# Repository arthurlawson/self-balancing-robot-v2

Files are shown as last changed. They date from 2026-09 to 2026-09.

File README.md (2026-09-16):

# 🤖 Self-Balancing Robot V2

### A Drivable Self-Balancing Robot That Screams When It Falls!

An advanced self-balancing robot utilizing the **ESP32-S3 (N16R8)** computing core, driven by a custom **Kalman Filter** and high-frequency **PID control loop** system.

This project features a fully **custom-designed main controller PCB, proudly sponsored and manufactured by JLCPCB**.

Built entirely within the PlatformIO ecosystem, this hardware platform integrates an MPU6050 IMU, DRV8833 motor driver, 2S LiPo battery safety logic, lighting, and onboard speaker playback systems.

---

## Core Features

*   **Advanced Estimation:** Custom Kalman Filter implementation paired with an MPU6050 IMU for precise roll angle determination.
*   **Wireless Remote Control:** Directional steering control handled over a dedicated **ESP-NOW** wireless connection.
*   **Motion:** Dual-motor balancing algorithms with custom gain scheduling to aid in active control.
*   **Hardware Protection:** Automated motor shutdown constraints to prevent destructive runaway crashes.
*   **Power Management:** Active voltage checks safeguarding the 2S LiPo system from dropping beneath unsafe cell margins.
*   **Audio & Visuals:** Integrated 2P edison filament LED's with status animations alongside audio playback to make the robot scream.

---

## Quick Navigation Hub

To get started with assembling or programming the robot, navigate to the specific setup guides below:

*   **[Firmware Setup & Deployment](./firmware/SETUP_GUIDE.md):** Complete code overview, configuration walkthrough for `config.h`, custom audio formatting parameters, and PlatformIO flashing instructions.
*   **[Hardware Production & Assembly](./hardware/SETUP_GUIDE.md):** Access to print-ready `.3mf` files, raw SolidWorks CAD models, custom KiCad schematics, and factory-ready Gerber packages.
*   **[Bill of Materials (BOM)](./hardware/BOM.md):** The complete physical and electrical component checklist required to buy, print, and manufacture the robot.

---

## Project License

This repository is distributed under a custom **Non-Commercial Open-Source License**. 

*   **Personal & Educational Use:** Freely allowed to modify, merge, and run the code/hardware assets.
*   **Commercial Use:** Strictly prohibited from being sold, leased, or utilized for paid product development without explicit written consent from the copyright holder.

*See the full terms inside the accompanying [LICENSE](./LICENSE) file.*

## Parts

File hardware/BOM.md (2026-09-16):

# Bill of Materials (BOM)

This document tracks all electronic, drivetrain, mechanical, and structural components required to fully manufacture and assemble the robot.

---

## 1. Core Electronics & Custom PCB Components

These components populate the custom controller PCB fabrications:
*   **Microcontroller:** ESP32-S3 (N16R8 Development Board variant)
*   **Inertial Measurement Unit (IMU):** MPU6050 Module (Breakout board style)
*   **Motor Driver Module:** DRV8833 Dual H-Bridge Motor Driver
*   **Power Regulation Module:** MPM3610 3.3V Buck Regulator (Highly efficient synchronous step-down)
*   **Peripherals:** Onboard 4-ohm Speaker, a 2P edison filament light setup connected to the top shelf
*   **Passives Checklist:** Assorted resistors (including voltage dividers for battery sensing tracking lines), capacitors, tactile buttons, and male/female header pins

---

## 2. Drivetrain & Power Systems

*   **Motors:** 2x TT Dual-Shaft DC Gearbox Motors (Yellow hobby style motors)
*   **Power Source:** 2S LiPo Battery (7.4V nominal, 8.4V max)
*   **Switching:** Main power toggle switch

---

## 3. Mechanical Fasteners

*   **Chassis Assembly:** M3 Hex Screws (Assorted lengths) and nuts, and M3 brass heat set inserts
*   **Motor Mount Fasteners:** M3 Screws and nuts compatible with standard TT motor chassis slots

---

## 4. Fabrication Components & Materials

*   **Custom PCB Manufacturing (`/electronics/fabrication`):** Main trace layout designed for manufacturing directly by **JLCPCB** using the provided `gerbers.zip` archive.
*   **Structural Rigid Printing Parts (`/cad/3d_prints`):** Printed entirely in **PLA+** for impact protection to withstand crashes when the robot falls over and screams.
    *   *Includes components:* BackPiece, FrontFacePiece, InnerChassis, LightDiffuser, MiddleHeadCover, TopShelf, and WheelRim.
*   **Traction Components (`/cad/3d_prints`):** `WheelTread.3MF` **must be manufactured in TPU** by **JLCPCB** to guarantee better balancing traction.

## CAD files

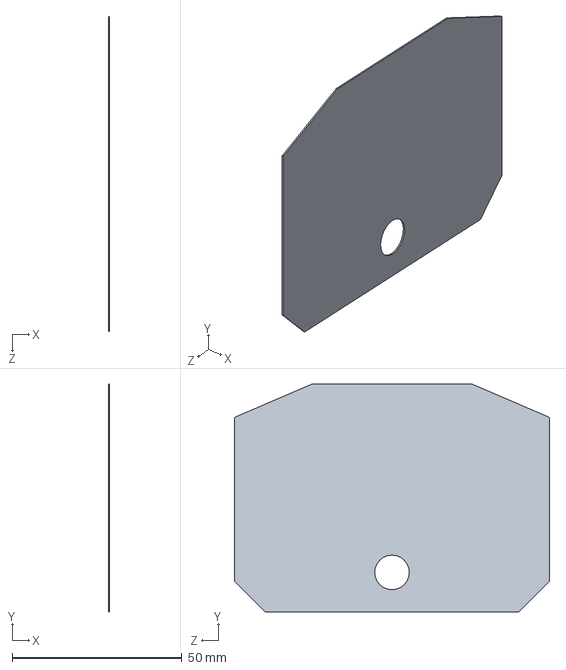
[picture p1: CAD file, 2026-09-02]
hardware/cad/source/solidwork_files/LightDiffuser.SLDPRT
0.4 x 67.2 x 92.9 mm

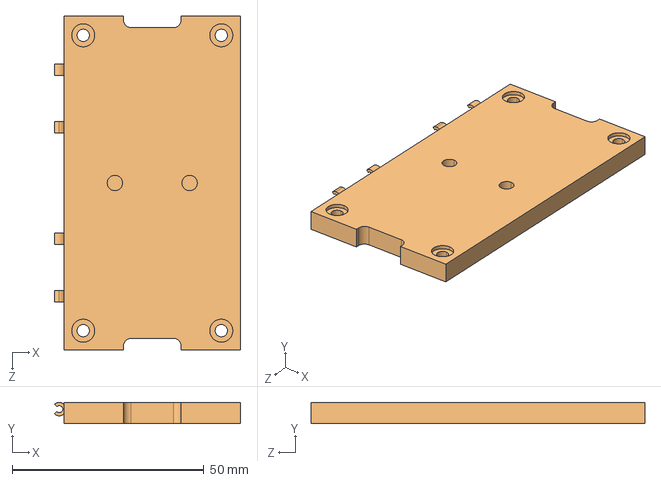
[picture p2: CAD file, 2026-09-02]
hardware/cad/source/step_files/TopShelf.STEP
48.5 x 5.58 x 87.0 mm

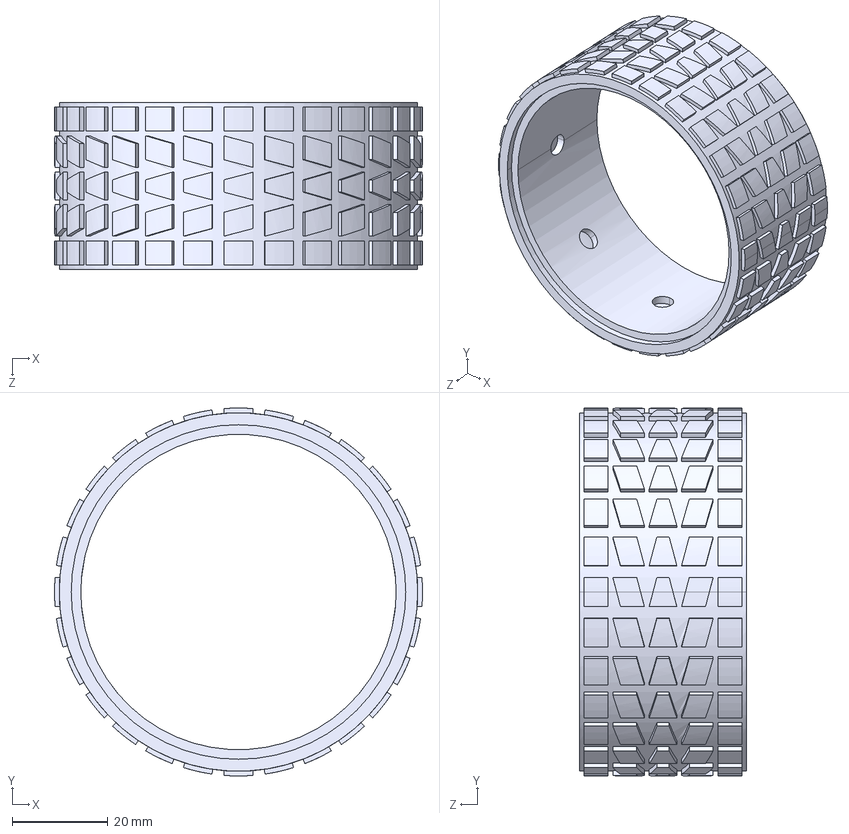
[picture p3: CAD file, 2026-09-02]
hardware/cad/source/step_files/WheelTread.STEP
77.0 x 77.0 x 35.0 mm

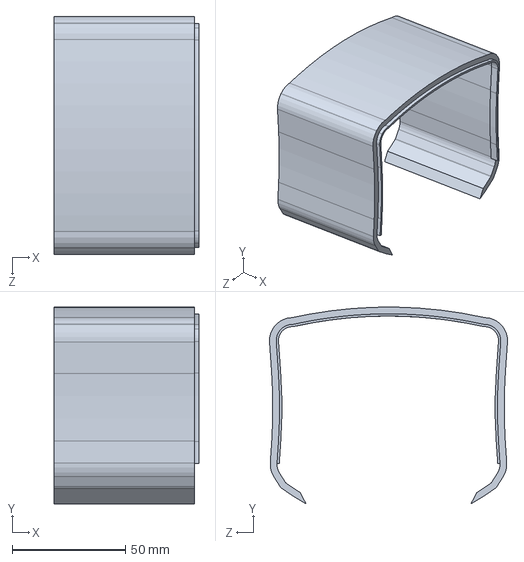
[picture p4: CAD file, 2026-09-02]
hardware/cad/source/solidwork_files/MiddleHeadCover.SLDPRT
64.0 x 86.9 x 105.1 mm

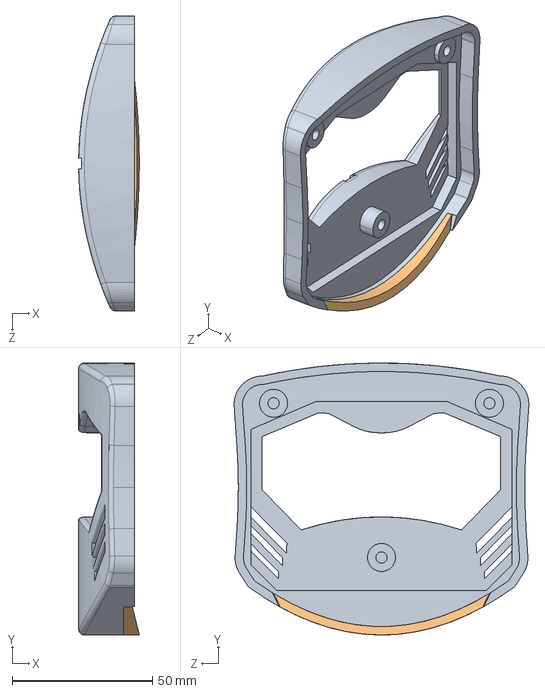
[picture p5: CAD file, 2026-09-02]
hardware/cad/source/step_files/FrontFacePiece.STEP
21.6 x 97.0 x 105.2 mm

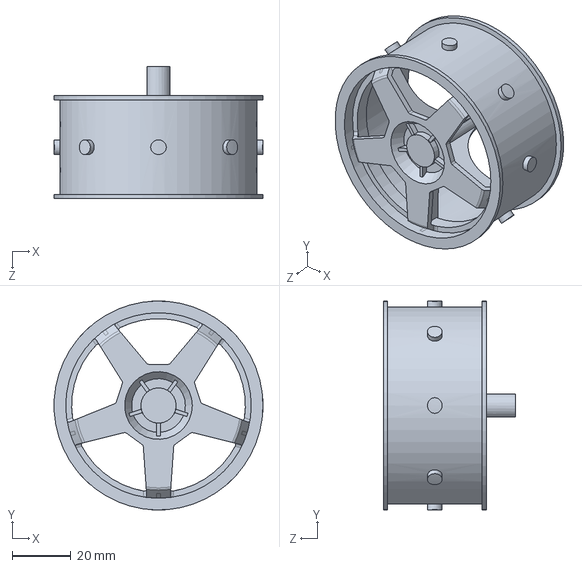
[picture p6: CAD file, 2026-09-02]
hardware/cad/source/solidwork_files/WheelRim.SLDPRT
71.0 x 71.0 x 45.0 mm

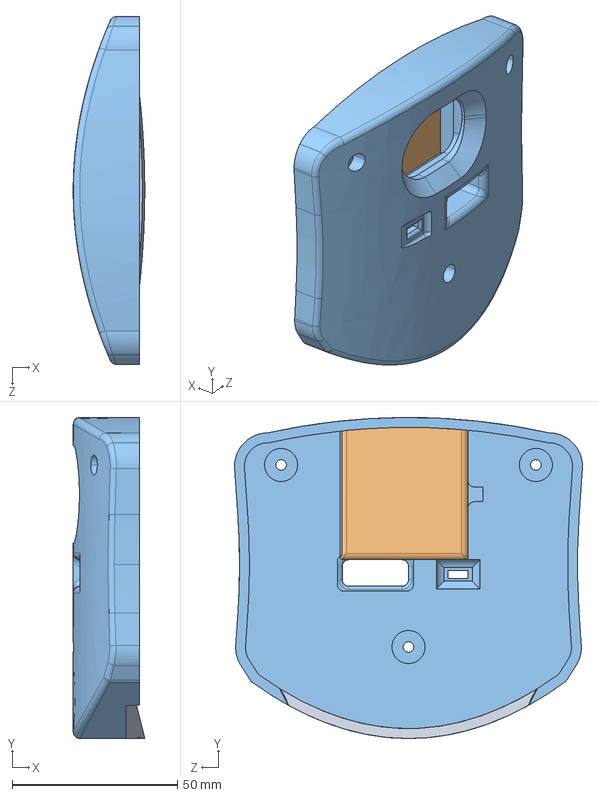
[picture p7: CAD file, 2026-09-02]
hardware/cad/source/step_files/BackPiece.STEP
21.7 x 97.0 x 105.2 mm

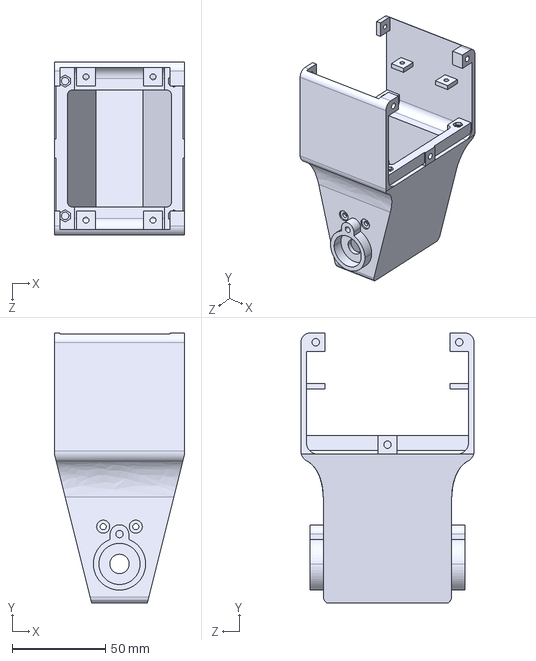
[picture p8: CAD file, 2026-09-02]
hardware/cad/source/step_files/InnerChassis.STEP
70.0 x 145.0 x 93.0 mm

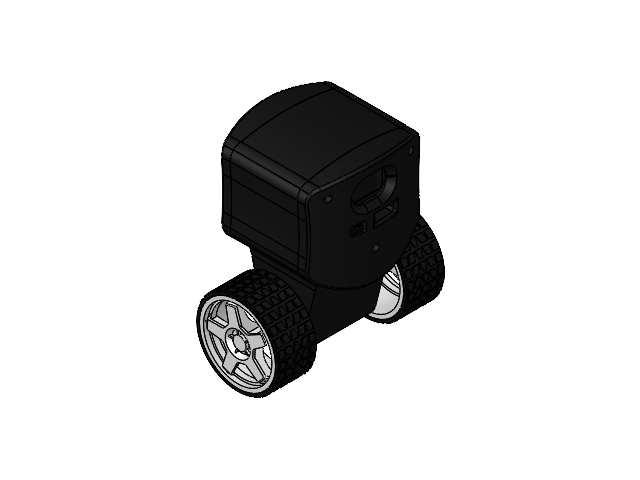
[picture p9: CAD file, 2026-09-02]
hardware/cad/source/solidwork_files/FullAssembly.SLDASM
InnerChassis
WheelRim x 2
WheelTread x 2
FrontFacePiece
CP_Radial_D63mm_P250mm.step
R_Axial_DIN0207_L63mm_D25mm_P762mm_Horizontal.step x 8
PinHeader_1x01_P254mm_Vertical.step x 8
PinHeader_1x02_P254mm_Vertical.step x 2
PinHeader_1x06_P254mm_Vertical.step x 2
C_Disc_D50mm_W25mm_P500mm.step x 3
PinHeader_1x08_P254mm_Vertical.step
TO-92_Inline_Narrow.step x 2
CP_Radial_D80mm_P380mm.step
PinHeader_1x04_P254mm_Vertical.step
esp32_self_balancing_robot_copper.step
esp32_self_balancing_robot_pad.step
esp32_self_balancing_robot_silkscreen.step
esp32_self_balancing_robot_silkscreen-0.step
esp32_self_balancing_robot_soldermask.step
esp32_self_balancing_robot_soldermask-1.step
esp32_self_balancing_robot_PCB.step
Gearbox.STEP x 2
output shaft.STEP x 2
motor.STEP x 2
LightDiffuser
BackPiece
HexNylonStandoff x 4
TopShelf
MiddleHeadCover

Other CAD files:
hardware/cad/source/solidwork_files/TopShelf.SLDPRT
hardware/cad/source/solidwork_files/WheelTread.SLDPRT
hardware/cad/source/step_files/LightDiffuser.STEP
hardware/cad/source/solidwork_files/BackPiece.SLDPRT
hardware/cad/source/solidwork_files/FrontFacePiece.SLDPRT
hardware/cad/source/step_files/MiddleHeadCover.STEP
hardware/cad/source/solidwork_files/InnerChassis.SLDPRT
hardware/cad/source/step_files/WheelRim.STEP
hardware/cad/3d_prints/BackPiece.3mf
hardware/cad/3d_prints/FrontFacePiece.3mf
hardware/cad/3d_prints/InnerChassis.3mf
hardware/cad/3d_prints/LightDiffuser.3mf
hardware/cad/3d_prints/MiddleHeadCover.3mf
hardware/cad/3d_prints/TopShelf.3mf
hardware/cad/3d_prints/WheelRim.3MF
hardware/cad/3d_prints/WheelTread.3MF

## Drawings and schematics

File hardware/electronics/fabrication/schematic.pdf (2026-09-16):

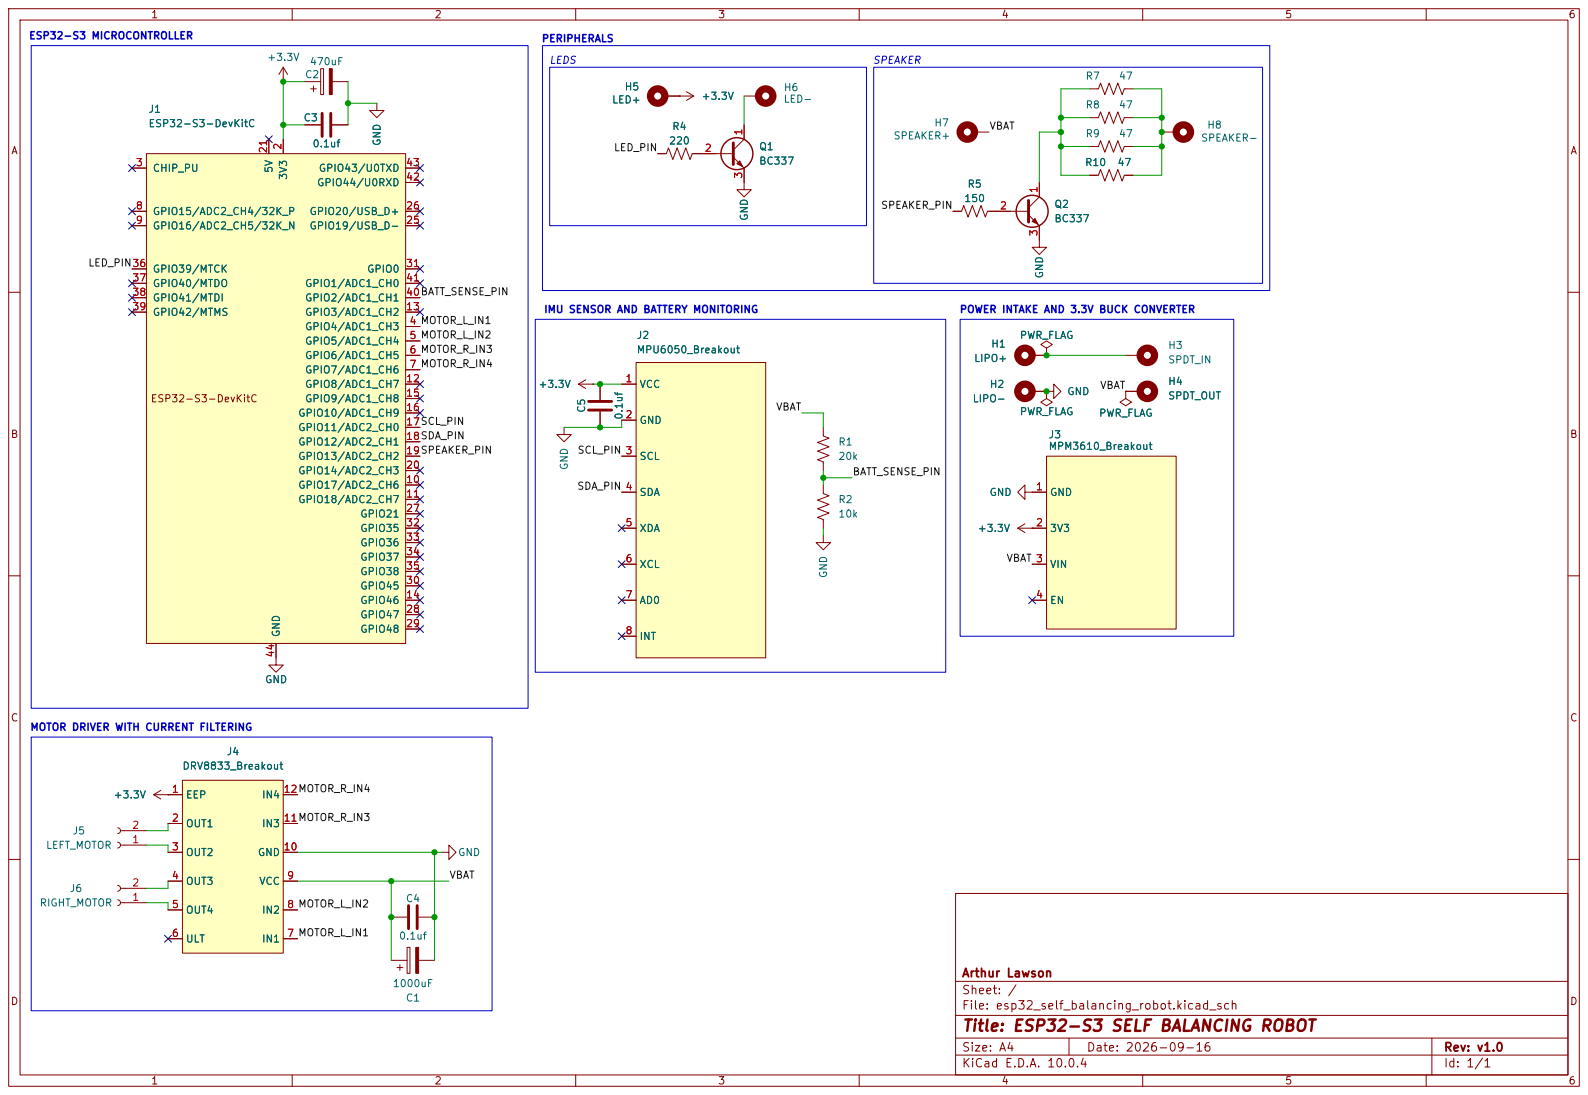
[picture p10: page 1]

PERIPHERALS MOTOR DRIVER WITH CURRENT FILTERING

Arthur Lawson
Sheet: /
File: esp32_self_balancing_robot.kicad_sch
Title: ESP32-S3 SELF BALANCING ROBOT

Size: A4 | Rev: v1.0
KiCad E.D.A. 10.0.4 | Id: 1/1

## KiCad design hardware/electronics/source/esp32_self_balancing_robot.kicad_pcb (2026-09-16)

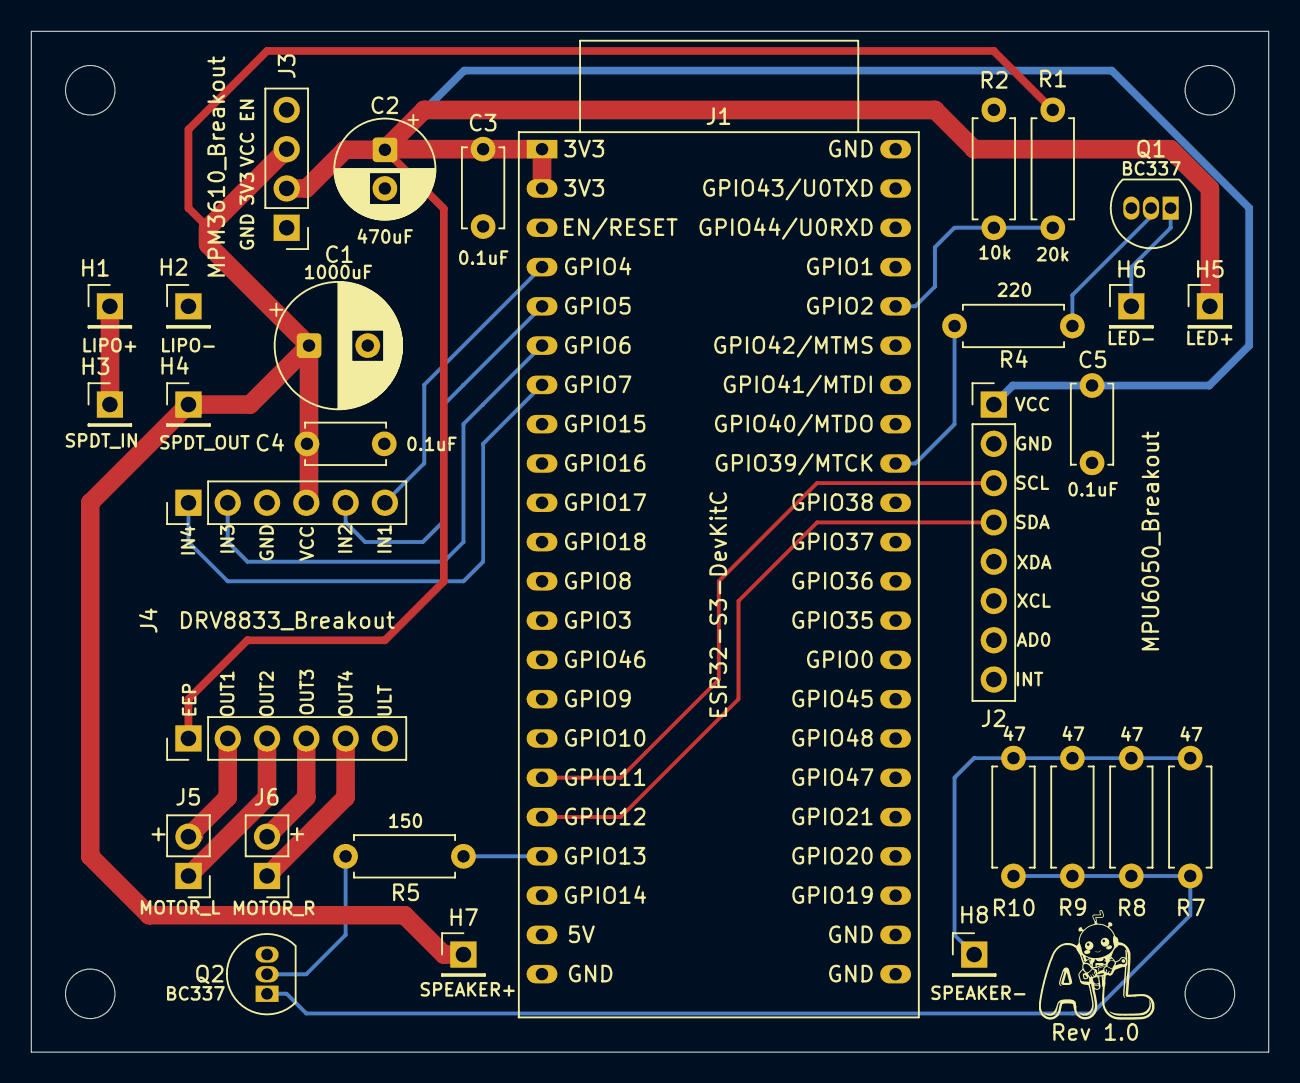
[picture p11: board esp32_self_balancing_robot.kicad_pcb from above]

Board: 2 copper layers, 80.0 x 66.0 mm, 29 parts (0 on the bottom side), 18 nets.

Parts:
C1: 1000uF; CP_Radial_D8.0mm_P3.80mm
C2: 470uF; CP_Radial_D6.3mm_P2.50mm
C3, C4, C5: 0.1uf; C_Disc_D5.0mm_W2.5mm_P5.00mm
H1: LIPO+; PinHeader_1x01_P2.54mm_Vertical
H2: LIPO-; PinHeader_1x01_P2.54mm_Vertical
H3: SPDT_IN; PinHeader_1x01_P2.54mm_Vertical
H4: SPDT_OUT; PinHeader_1x01_P2.54mm_Vertical
H5: LED+; PinHeader_1x01_P2.54mm_Vertical
H6: LED-; PinHeader_1x01_P2.54mm_Vertical
H7: SPEAKER+; PinHeader_1x01_P2.54mm_Vertical
H8: SPEAKER-; PinHeader_1x01_P2.54mm_Vertical
J1: ESP32-S3-DevKitC
J2: MPU6050_Breakout; PinHeader_1x08_P2.54mm_Vertical
J3: MPM3610_Breakout; PinHeader_1x04_P2.54mm_Vertical
J4: DRV8833_Breakout; PinHeader_1x06_P2.54mm_Vertical
J5: LEFT_MOTOR; PinHeader_1x02_P2.54mm_Vertical
J6: RIGHT_MOTOR; PinHeader_1x02_P2.54mm_Vertical
Q1, Q2: BC337; TO-92_Inline
R1: 20k; R_Axial_DIN0207_L6.3mm_D2.5mm_P7.62mm_Horizontal
R2: 10k; R_Axial_DIN0207_L6.3mm_D2.5mm_P7.62mm_Horizontal
R4, R5: 220; R_Axial_DIN0207_L6.3mm_D2.5mm_P7.62mm_Horizontal
R7, R8, R9, R10: 47; R_Axial_DIN0207_L6.3mm_D2.5mm_P7.62mm_Horizontal

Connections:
+3.3V: C2.1, C3.2, C5.1, H5.1 (1_1), J1.1 (3V3), J1.2 (3V3), J2.1 (VCC), J3.2 (3V3), J4.1 (EEP)
/BATT_SENSE_PIN: J1.40 (GPIO2/ADC1_CH1), R1.1, R2.1
/LED_PIN: J1.36 (GPIO39/MTCK), R4.2
/SCL_PIN: J1.17 (GPIO11/ADC2_CH0), J2.3 (SCL)
/SDA_PIN: J1.18 (GPIO12/ADC2_CH1), J2.4 (SDA)
/SPEAKER_PIN: J1.19 (GPIO13/ADC2_CH2), R5.2
/VBAT: C1.1, C4.2, H4.1 (1_1), H7.1 (1_1), J3.3 (VIN), R1.2
GND: C1.2, C2.2, C3.1, C4.1, C5.2, H2.1 (1_1), J1.22 (GND), J1.23 (GND), J1.24 (GND), J1.44 (GND), J2.2 (GND), J3.1 (GND), Q1.3 (E), Q2.3 (E), R2.2
unnamed: H1.1 (1_1), H3.1 (1_1)
unnamed: H8.1 (1_1), R7.1, R8.1, R9.1, R10.1
unnamed: J4.2 (OUT1), J5.2
unnamed: J4.3 (OUT2), J5.1
unnamed: J4.4 (OUT3), J6.2
unnamed: J4.5 (OUT4), J6.1
unnamed: Q1.2 (B), R4.1
unnamed: H6.1 (1_1), Q1.1 (C)
unnamed: Q2.2 (B), R5.1
unnamed: Q2.1 (C), R7.2, R8.2, R9.2, R10.2

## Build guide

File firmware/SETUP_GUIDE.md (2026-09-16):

# Firmware Setup & Deployment Guide

This guide provides step-by-step instructions for configuring, compiling, and flashing the firmware for both the self-balancing robot and its remote transmitter using **PlatformIO**.

---

## Prerequisites & Installation

Before flashing either device, ensure you have the following toolchain installed:
1. **VS Code** with the **PlatformIO IDE** extension installed.
2. An appropriate USB cable to connect your ESP32 boards directly to your computer.

---

## 1. Remote Transmitter Firmware

The remote controller firmware handles directional steering commands and pairs to the robot over ESP-NOW.

### Understanding `config.h` (Remote)
All transmitter configurations are managed centrally inside `firmware/remote_firmware/include/config.h`.

* **WIRELESS NETWORK [DO NOT MODIFY]:** Maps the primary Wi-Fi communication channel and broadcast pairing destination. Altering this breaks connection pairing with the robot.

* **SYSTEM TIMING:** Configures telemetry frequency. `SEND_INTERVAL_MS` handles continuous packet rates, while `CONNECTION_LED_TIMEOUT_MS` controls how long the pairing LED stays lit after a successful ACK packet response.

* **HARDWARE PIN MAPPING:** Defines the directional pushbuttons and system state feedback configurations.

### How to Flash:
1. Open the **Master Root Repo** workspace folder in VS Code.
2. Open the **PlatformIO sidebar tool** (the alien head icon).
3. Locate and expand the **`env:remote_firmware`** environment under the Project Tasks list.
4. Connect your remote transmitter board via USB.
5. Click **Build**, followed by **Upload**.

---

## 2. Robot Firmware & Global Configuration

The robot firmware handles the core balancing logic, motor kinematics, audio playback, and system safety thresholds.

### Understanding `config.h` (Robot)
All system adjustments are managed centrally inside `firmware/robot_firmware/include/config.h`.

* **SYSTEM BOOT & TIMING [DO NOT MODIFY]:** Controls the core runtime math. `BOOT_TIME_MS` defines the initialization window before the robot engages. Altering loop intervals will disrupt hardware timers and destabilize the PID calculations.

* **HARDWARE PIN MAPPING:** Defines the layout for motor drivers, IMU I2C lines, and peripherals. *Warning: Do not alter if using my custom designed PCB.*

* **SAFETY THRESHOLDS:** Protects your hardware. `ACTIVATION_ANGLE` and `STOP_ANGLE` determine when motors engage or shut down to prevent runaway crashes, while `BATT_LOW_THRESHOLD` safeguards the 2S LiPo battery from over-discharging below a safe operating voltage.

* **PID LOOP TUNING:** Fine-tunes the balance responsiveness via Proportional (`KP`), Integral (`KI`), and Derivative (`KD`) gains.

* **MOTION & KINEMATICS:** Adjusts behavior when moving or executing turns, including motor bias adjustments (`LEFT_TRIM` / `RIGHT_TRIM`) to counteract minor mechanical drift.

* **AUDIO & LED CONFIGURATION:** Manages peripheral behaviors, capping volume ceilings and maximum LED brightness constraints for thermal protection.

### How to Flash:
1. Open the **PlatformIO sidebar tool** in VS Code.
2. Locate and expand the **`env:robot_firmware`** environment.
3. Connect your self-balancing robot board via USB.
4. Click **Build**, followed by **Upload**.

---

## 3. Custom Audio & Filesystem Image (LittleFS)

The robot plays raw audio samples directly from internal flash storage using optimized timing. To prevent static distortion or incorrect pitch playback, follow these instructions precisely:

### Step 1: Prepare Your Audio Files
Custom audio clips **must** meet these strict hardware constraints:
* **Format:** `.wav` (Unsigned 8-bit PCM)
* **Channels:** Mono (1 channel)
* **Sample Rate:** 11,025 Hz *(Matches `SAMPLE_DELAY_MICROS = 91` in `config.h`)*

1. **Get Audio:** Download your own audio clip from online (This could be in an MP3 or WAV format)
2. **Convert Audio:** Head to the [Online-Convert Audio to WAV](https://online-convert.com) tool.
3. **Configure Settings:** Under **Optional Settings**, apply these strict conversion rules:
   * Change bit depth: **`8 Bit`**
   * Change audio sample rate: **`11025 Hz`**
   * Change audio channels: **`Mono`**
4. **Download:** Click **Start**, then download your formatted `.wav` file.

### Step 2: Manage the Project Assets
PlatformIO expects a specific folder structure to compile binary filesystem data.
1. Place your converted `.wav` audio files directly inside the dedicated **`firmware/robot_firmware/data/`** directory.
2. Ensure you name them with the prefix "audio(NUMBER).wav", beginning at audio0.wav, then audio1.wav, then audio2.wav and so on

### Step 3: Flash the Filesystem
Your `platformio.ini` is pre-configured to handle the layout using the target flag `board_build.filesystem = littlefs`.

1. Open the **PlatformIO sidebar tool**.
2. Expand your **`env:robot_firmware`** environment entry.
3. Expand the **Platform** tasks dropdown list.
4. Click **Upload Filesystem Image**.

**Important Note:** Flashing the filesystem will completely overwrite any files currently stored on the chip. Ensure all default files your robot's source code expects to find remain in the `data/` folder alongside your custom sounds before hitting upload.

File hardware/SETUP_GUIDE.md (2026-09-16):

# Robot Hardware, CAD & Electronics

This directory contains the full mechanical design assets and electronic manufacturing data required to fabricate and assemble the physical self-balancing robot.

---

## 1. 3D CAD & Mechanical Design (`/cad`)

The structural chassis parts are modeled in SolidWorks. Print-ready formats and raw design models are split by intent:

* **3D Printing Files (`/3d_prints`):** Contains **`.3mf` format files** ready to import into your slicer (Bambu Studio, PrusaSlicer, OrcaSlicer, etc.).
  * *Includes parts:* BackPiece, FrontFacePiece, InnerChassis, LightDiffuser, MiddleHeadCover, TopShelf, WheelRim, and WheelTread.

* **Source Models (`/source`):** 
  * `solidwork_files/` - Raw project design history files for modifications.
  * `step_files/` - Universal solid formats to import into alternate CAD software (Fusion 360, Onshape, Inventor, etc.).

---

## 2. Electronics & Custom Controller (`/electronics`)

This layout contains the electrical schematic routing and custom PCB trace blueprints for the core onboard robot controller.

* **Fabrication Packages (`/fabrication`):**
  * `gerbers.zip` - Production data package ready to drop directly into production engines (JLCPCB)
  * `schematic.pdf` - Document for trace validation and testing diagnostics.

* **Source Blueprints (`/source`):**
  * Contains the editable **KiCad project project assets** (`.kicad_pcb`, `.kicad_sch`) alongside custom component symbols utilized for the board design routing layout.

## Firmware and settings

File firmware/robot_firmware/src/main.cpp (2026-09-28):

/**
 * @file main.cpp
 * @brief Entry point for the Self Balancing Robot
 * 
 * @author Arthur Lawson
 */

#include <config.h>
#include "utils/kalman_filter/kalman_filter.h"
#include "utils/pid_controller/pid_controller.h"
#include "drivers/motor_driver/drv8833.h"
#include "drivers/audio_driver/audio_driver.h"
#include "services/imu_service/imu_service.h"
#include "services/led_service/led_service.h"
#include "services/power_service/power_service.h"
#include "services/remote_service/remote_service.h"
#include "system/robot_controller/robot_controller.h"

// UTILS
KalmanFilter kf;
PidController pid;

// DRIVERS
DRV8833 motors(IN1_PIN, IN2_PIN, IN3_PIN, IN4_PIN);
AudioDriver speaker(SPEAKER_PIN);

// SERVICES
ImuService imuSvc(kf);
LedService ledSvc(LED_PIN);
PowerService pwrSvc(BATT_PIN, ledSvc);
RemoteService remote;

// ROBOT CONTROL SYSTEMS
RobotController robot(imuSvc, ledSvc, pwrSvc, motors, pid, kf, speaker);

// HARDWARE TIMER
volatile bool timerFlag = false;
hw_timer_t *timer = NULL;

void ARDUINO_ISR_ATTR onTimer() {
  timerFlag = true;
}

void setup() {
  Serial.begin(115200);
  delay(200);

  Serial.println("\n[BOOT] Power rails stabilized. Initiating hardware mounts...");

  randomSeed(analogRead(0));

  // 2. Safely initialize your speaker driver to clamp your transistor gate
  if (!speaker.Begin()) {
    Serial.println("[BOOT] WARNING: Audio Driver mount failed to clear filesystem.");
  }

  if (!imuSvc.Begin(SDA_PIN, SCL_PIN)) {
    while (1) {
      Serial.println("IMU Initialization Failed.");
      delay(1000);
    }
  }

  ledSvc.Begin();
  pwrSvc.Begin();
  remote.Begin(robot);

  robot.Begin();

  timer = timerBegin(0, TIMER_PRESCALER, true);
  timerAttachInterrupt(timer, &onTimer, true);
  timerAlarmWrite(timer, TIMER_ALARM_US, true);
  timerAlarmEnable(timer);

  Serial.println("System Core Ready!");
}

void loop() {
  if (timerFlag) {
    timerFlag = false;

    ledSvc.Update();
    imuSvc.Update();
    remote.Update();
    robot.Update();
  }
}

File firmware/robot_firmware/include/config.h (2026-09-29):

/**
 * @file config.h
 * @brief Global configuration constants for the robot.
 * 
 * @author Arthur Lawson
 */

#pragma once

#include <cstdint>

// =====================================================================================
// SYSTEM BOOT
// =====================================================================================
// *** Adjust as wanted

// Global initialization sequence duration before the robot begins balancing (in milliseconds)
static constexpr uint16_t BOOT_TIME_MS = 1500;

// =====================================================================================
// SYSTEM TIMING
// =====================================================================================
// *** WARNING: Changing loop timing will disrupt the hardware timers and destabilize the PID loop.

// Loop update interval in milliseconds
static constexpr float DELTA_T_MS = 5.0f;

// Loop update interval in seconds
static constexpr float DELTA_T_SEC = DELTA_T_MS / 1000.0f;

// Hardware timer alarm interval in microseconds
static constexpr uint32_t TIMER_ALARM_US = static_cast<uint32_t>(DELTA_T_MS * 1000.0f);

// Timer prescaler clock divider (80MHz / 80 = 1 tick per microsecond)
static constexpr uint16_t TIMER_PRESCALER = 80;

// =====================================================================================
// HARDWARE PIN MAPPING
// =====================================================================================
// *** Adjust these pins to match your physical hardware wiring layout
// *** WARNING: If you use the PCB that I designed, do not change these

// Power monitoring
static constexpr uint8_t BATT_PIN = 2;

// Motor driver (H-Bridge)
static constexpr uint8_t IN1_PIN = 4;
static constexpr uint8_t IN2_PIN = 5;
static constexpr uint8_t IN3_PIN = 6;
static constexpr uint8_t IN4_PIN = 7;

// I2C Communication (IMU)
static constexpr uint8_t SCL_PIN = 11;
static constexpr uint8_t SDA_PIN = 12;

// Peripherals
static constexpr uint8_t SPEAKER_PIN = 13;
static constexpr uint8_t LED_PIN = 39;

// =====================================================================================
// SAFETY THRESHOLDS
// =====================================================================================
// *** Adjust these parameters to safeguard your robot during testing

// Angle in degrees to where the motors engage to start balancing
static constexpr float ACTIVATION_ANGLE = 3.0f;

// Angle in degrees where the motors shut off to prevent runaway crashes 
static constexpr float STOP_ANGLE = 50.0f;

// At this battery level for the 2S lipo of 8.4V, the robot will lock itself off (5.5V is too low for good motor function)
static constexpr float BATT_LOW_THRESHOLD = 5.5f;

// =====================================================================================
// PID CONTROL LOOP TUNING
// =====================================================================================
// *** Adjust these parameters to stabilize your robot's balance

// Target balance pitch angle in degrees (accounts for center of mass offset)
static constexpr float DEFAULT_SETPOINT = 1.3f; 

// Proportional gain
static constexpr float KP = 30.0f;

// Integral gain
static constexpr float KI = 0.0f;

// Derivative Gain
static constexpr float KD = 0.04f;

// Minimum PWM to overcome static motor friction
static constexpr float MIN_PWM = 30.0f;

// =====================================================================================
// MOTION AND KINEMATICS
// =====================================================================================
// *** Adjust these values to change how the robot behaves when moving or turning

// The driving lean angle
static constexpr float MAX_DRIVE_LEAN_DEG = 7.0f;

// The speed at which the robot can instantly lean the other direction to brake
static constexpr float SPEED_TO_CONSIDER_BRAKE = 0.12f;

// Acceleration rate for speed transitions
static constexpr float MOVEMENT_RAMP_RATE = 0.004f;

// Deceleration rate when shifting directions quickly
static constexpr float BRAKING_RAMP_RATE = 0.35f;

// PWM offset injected to execute turns
static constexpr float TURN_SPEED_OFFSET = 30.0f;

// Motor bias compensation that scales each motor strength (In this case the left motor gets a 10% boost)
static constexpr float LEFT_TRIM = 1.1f;
static constexpr float RIGHT_TRIM = 1.0f;

// =====================================================================================
// AUDIO CONFIGURATION
// =====================================================================================
// *** Adjust the sample rates, volume ceilings and playback rules

// Global volume limit ceiling (Value ranges from 0 to 255)
static constexpr uint32_t MAX_VOLUME = 180;

// Minimum time required between consecutive playbacks (in milliseconds)
static constexpr uint32_t MIN_BETWEEN_PLAYS_MILLIS = 5000;

// Maximum allowed duration for a single audio clip
static constexpr uint32_t MAX_PLAY_DURATION_MILLIS = 3000;
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

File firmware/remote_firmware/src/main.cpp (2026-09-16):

/**
 * @file main.cpp
 * @brief Entry point for the Self Balancing Robot Remote
 * 
 * @author Arthur Lawson
 */

#include <Arduino.h>
#include <config.h>
#include <esp_now.h>
#include <WiFi.h>
#include <esp_wifi.h>
#include "protocol.h"

ControlPacket msg;
esp_now_peer_info_t peerInfo;
unsigned long lastAckTime = 0;

void OnDataSent(const uint8_t* mac, esp_now_send_status_t status) {
    if (status == ESP_NOW_SEND_SUCCESS) {
        lastAckTime = millis();
    }
}

void setup() {
    Serial.begin(115200);
    // LED
    pinMode(LED_PIN, OUTPUT);
    digitalWrite(LED_PIN, LOW);

    // Buttons
    pinMode(FWD_PIN, INPUT_PULLUP);
    pinMode(BWD_PIN, INPUT_PULLUP);
    pinMode(LFT_PIN, INPUT_PULLUP);
    pinMode(RGT_PIN, INPUT_PULLUP);

    WiFi.mode(WIFI_STA);

    esp_wifi_set_channel(1, WIFI_SECOND_CHAN_NONE);

    if (esp_now_init() != ESP_OK) return;

    esp_now_register_send_cb(OnDataSent);

    // Register peer
    memcpy(peerInfo.peer_addr, BROADCAST_ADDRESS, 6);
    peerInfo.channel = 1;
    peerInfo.encrypt = false;

    // Add peer
    if (esp_now_add_peer(&peerInfo) != ESP_OK) {
        Serial.println("Failed to add peer!");
        return;
    }

    Serial.println("ESP-NOW initialized and peer successfully added!");
}

void loop() {
  bool fwd = (digitalRead(FWD_PIN) == LOW);
  bool bwd = (digitalRead(BWD_PIN) == LOW);
  bool lft = (digitalRead(LFT_PIN) == LOW);
  bool rgt = (digitalRead(RGT_PIN) == LOW);

  if (fwd && bwd) { fwd = false; bwd = false; }
  if (lft && rgt) { lft = false; rgt = false; }

  if (fwd && lft)        msg.command = '1';
  else if (fwd && rgt)   msg.command = '2';
  else if (bwd && lft)   msg.command = '3';
  else if (bwd && rgt)   msg.command = '4';
  else if (fwd)          msg.command = 'F';
  else if (bwd)          msg.command = 'B';
  else if (lft)          msg.command = 'L';
  else if (rgt)          msg.command = 'R';
  else                   msg.command = 'I';

  if (millis() - lastAckTime < 200)
  {
    digitalWrite(LED_PIN, HIGH);
  } else {
        digitalWrite(LED_PIN, LOW);
    }

    static unsigned long lastSendTime = 0;
    if (millis() - lastSendTime > 50) { // send every 50ms - Half of watchdog timout in robot firmware
        lastSendTime = millis();
        esp_now_send(BROADCAST_ADDRESS, (uint8_t*) &msg, sizeof(msg));

        if (msg.command != 'I') {
            Serial.printf("Transmitting: %c\n", msg.command);
        }
    }
}

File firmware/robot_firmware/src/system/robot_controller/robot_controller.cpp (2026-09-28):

#include <config.h>
#include "robot_controller.h"
#include "utils/math_utils.h"

RobotController::RobotController(ImuService& imuSvc, LedService& ledSvc, PowerService& pwrSvc, DRV8833& motors, PidController& pid, 
                                 KalmanFilter& kf, AudioDriver& speaker)
    : _imuSvc(imuSvc), _ledSvc(ledSvc), _pwrSvc(pwrSvc), _motors(motors), _pid(pid), _kf(kf), _curState(RobotState::FALLEN),
      _speaker(speaker) {}

void RobotController::Begin() {
    _curState = RobotState::FALLEN;
    Reset();
}

void RobotController::Update() {
    // ===========================================================================
    // GET ORIENTATION
    // ===========================================================================
    float curAngle = _imuSvc.GetFilteredRoll();
    float safetyError = fabs(curAngle - DEFAULT_SETPOINT);

    // ===========================================================================
    // SAFETY CHECKS AND FALLEN CHECKS
    // ===========================================================================
    // Bootup alignment check
    if (!_ledSvc.IsBootComplete()) {
        _motors.StopBoth();
        return;
    }

    // Battery low check
    if (_curState == RobotState::BATTERY_LOW || _pwrSvc.IsBatteryLow()) {
        Reset();
        _curState = RobotState::BATTERY_LOW;
        _ledSvc.SetState(LedService::LED_BLINK_SLOW);
        _speaker.StopPlayback();
        return;
    }  

    // Fallen Check
    if (_curState != RobotState::FALLEN) {
        if (safetyError > STOP_ANGLE) {
            Reset();
            _curState = RobotState::FALLEN;
            _speaker.PlayRandomAudio();
            _ledSvc.SetState(LedService::LED_PULSING);
            return;
        }
    } else {
        if (safetyError <= ACTIVATION_ANGLE && _imuSvc.IsUpright()) {
            Reset();
            _speaker.StopPlayback();
            _ledSvc.SetState(LedService::LED_ON);
            _curState = RobotState::IDLE;
        } else {
            _motors.StopBoth();
            _ledSvc.SetState(LedService::LED_PULSING);
            return;
        }
    }    

    // ===========================================================================
    // INPUT AND VELOCITY TRACKING
    // ===========================================================================
    bool isDriving = (_curState == RobotState::FORWARD || _curState == RobotState::FORWARD_LEFT || _curState == RobotState::FORWARD_RIGHT ||
                      _curState == RobotState::BACKWARD || _curState == RobotState::BACKWARD_LEFT || _curState == RobotState::BACKWARD_RIGHT);

    int currentDriveDir = 0;
    float rawTarget = 0.0f;

    if (isDriving) {
        if (_curState == RobotState::FORWARD || _curState == RobotState::FORWARD_LEFT || _curState == RobotState::FORWARD_RIGHT) {
            rawTarget = MAX_DRIVE_LEAN_DEG;
            currentDriveDir = 1;
        } else {
            rawTarget = -MAX_DRIVE_LEAN_DEG;
            currentDriveDir = -1;
        }
    }

    bool isFlippingDirection = (currentDriveDir == -1 && _speedLeakAccumulator < -SPEED_TO_CONSIDER_BRAKE) || 
                               (currentDriveDir == 1 && _speedLeakAccumulator > SPEED_TO_CONSIDER_BRAKE);

    // ===========================================================================
    // TARGET LEAN AND SPEED MANAGEMENT
    // ===========================================================================
    float targetLeanAngle = DEFAULT_SETPOINT;

    if (isDriving) {
        _isDrivingInSameDir = ((rawTarget > 0.0f && _speedLeakAccumulator < -0.05f) ||
                               (rawTarget < 0.0f && _speedLeakAccumulator > 0.05f)) && !_isBrakingLock;
        
        if (_isDrivingInSameDir) {
            float speedLimitFactor = constrain(1.0f - (fabs(_speedLeakAccumulator) * 0.75f), 0.2f, 1.0f);
            targetLeanAngle = DEFAULT_SETPOINT + (rawTarget * speedLimitFactor);
        } else {
            _speedLeakAccumulator = 0.0f; 
            targetLeanAngle = DEFAULT_SETPOINT + rawTarget;
        }
    } else {
        _isBrakingLock = false;

        if (_currentTargetLean > DEFAULT_SETPOINT + 0.5f)      _currentBrakingLean = -1.5f; 
        else if (_currentTargetLean < DEFAULT_SETPOINT - 0.5f) _currentBrakingLean = 1.5f;
        else                                                    _currentBrakingLean *= 0.85f;
    }

    float dynamicTarget = targetLeanAngle + _currentBrakingLean;

    // Determine target interpolation speed
    float activeRampRate = MOVEMENT_RAMP_RATE;
    if (dynamicTarget == DEFAULT_SETPOINT || fabs(dynamicTarget - DEFAULT_SETPOINT) < fabs(_currentTargetLean - DEFAULT_SETPOINT)) {
        activeRampRate = BRAKING_RAMP_RATE; 
    }
    
    // If its flipping direction, dont interpolate slowly, else interpolate slowly
    if (isFlippingDirection) {
        _currentTargetLean = dynamicTarget;
        _isBrakingLock = true;
    } else {
        _currentTargetLean = ((1.0f - activeRampRate) * _currentTargetLean) + (activeRampRate * dynamicTarget);
    }

    // ===========================================================================
    // GAIN SCHEDULING
    // ===========================================================================
    float currentKp = KP, currentKd = KD, currentMinPwm = MIN_PWM;

    if (isFlippingDirection && safetyError > 0.8f) {
        currentKp *= 5.0f; 
        currentKd *= 4.0f; 
        currentMinPwm += 40.0f; 
    }

    _pid.SetKp(constrain(currentKp, 0.0f, 220.0f));
    _pid.SetKd(constrain(currentKd, 0.0f, 3.5f));
    currentMinPwm = constrain(currentMinPwm, 0.0f, 160.0f);

    // ===========================================================================
    // YAW CONFIGURATION (FOR TURNING)
    // ===========================================================================
    if (_curState == RobotState::LEFT) _yawTurnOffset = TURN_SPEED_OFFSET;
    else if (_curState == RobotState::RIGHT) _yawTurnOffset = -TURN_SPEED_OFFSET;
    else if (_curState == RobotState::FORWARD_LEFT || _curState == RobotState::BACKWARD_LEFT) _yawTurnOffset = TURN_SPEED_OFFSET * 0.35f;
    else if (_curState == RobotState::FORWARD_RIGHT || _curState == RobotState::BACKWARD_RIGHT) _yawTurnOffset = -TURN_SPEED_OFFSET * 0.35f; 
    else _yawTurnOffset = 0.0f;    

    bool isPureSpin = ((_curState == RobotState::LEFT || _curState == RobotState::RIGHT) && targetLeanAngle == DEFAULT_SETPOINT);
    static float smoothedYawOffset = 0.0f;
    smoothedYawOffset = isPureSpin ? _yawTurnOffset : (0.90f * smoothedYawOffset) + (0.10f * _yawTurnOffset); 

    // ===========================================================================
    // PID COMPUTATION AND DEADBAND
    // ===========================================================================
    float virtualAngle = curAngle - _currentTargetLean;
    float balancingOutput = _pid.Compute(virtualAngle, 255.0f);
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

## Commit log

2026-09-02 Add completed mechanical CAD and KiCad PCB fabrication assets
    [BackPiece.3mf, BackPiece.SLDPRT, BackPiece.STEP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]
2026-09-02 Implement DRV8833 dual brushed dc motor driver using slow decay brakes
2026-09-02 Implement 2D Linear Kalman Filter for sensor fusion of MPU6050 IMU data
2026-09-02 Implement IMU service to manage the MPU6050 IMU and Kalman Filtering to get filtered roll
2026-09-03 Implement PidController util with dynamic KI anti-windup clamping
2026-09-03 Implement LED Service with a basic state machine for set states of the LEDs
2026-09-03 Implement Power Service to aid in battery monitoring, and shutdown if battery is low.
2026-09-03 refactor: optimize kalman filter to act purely calculations by offloading the orientation guard to the controller
2026-09-03 feat: add gravity-vector check to prevent accidental recover when upside down
    [robot_controller.cpp]
2026-09-03 chore: fix wording in audio driver brief
2026-09-03 fix: move speaker pin grounding to global constructor to completely stop transistor startup leakage, and make it the first to be setup in main
    [audio_driver.cpp, main.cpp]
2026-09-03 fix(hardware): isolate audio pin to eliminate idle speaker overheating
    Overhauled peripheral hardware resource allocations to stop high-frequency clock corruption, register collisions, and noise leaks from reaching the low-side audio transistor switch.
    Key changes:
    - audio_driver: Migrated to native LEDC Channel 0 / Timer 0. Implemented a hard digital OUTPUT LOW ground shunt inside the constructor and StopPlayback() to prevent trace leakage.
    - drv8833: Migrated H-bridge inputs to native LEDC Channels 2-5 on Timer 2 (20kHz), removing the analogWrite() channel overlap that was accidentally driving the speaker.
    - led_service: Migrated filament bulb animations to native LEDC Channel 1 / Timer 1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
    [audio_driver.cpp, drv8833.cpp, led_service.cpp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]
2026-09-15 Implement working remote code, and control system for the Esp32 self balancing robot
2026-09-16 Fix robot controller logic to aid in balancing
    [robot_controller.cpp]
2026-09-16 Chore: move the low battery threshold to the config
2026-09-16 fix: electronic design layouts
    [esp32_self_balancing_robot.kicad_pcb, esp32_self_balancing_robot.kicad_sch]
2026-09-17 Refactor(RobotController & Config): Fine tune the details of the robot controller movement and PID tuning
2026-09-28 refactor: decouple driver architecture from legacy Arduino frameworks
2026-09-29 fix: add #include <cstdint> header file to provide fixed width integer types
    [config.h, power_service.cpp]
